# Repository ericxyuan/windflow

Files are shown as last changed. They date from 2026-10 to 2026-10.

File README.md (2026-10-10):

# Windflow desktop fan

Rev D is the current **150 mm CAD development candidate**, following the saved rotor-selection study. It uses one **T-Motor Pacer V4 P2406 Juicy 2060KV**, a custom swept/twisted five-blade impeller, one telemetry ESC, a flowing hollow enclosure and an integrated progressive outlet. Electronics retain the Rev C baseline. The active firmware, in the historical `WindflowRevC` folder, now binds calibration to the exact 150 mm rotor article with schema 5; rotor motion remains inhibited until physical commissioning requirements are met. The earlier 112 mm geometry is preserved.

Start with the [150 mm CAD decisions, validation, printing limits and remaining work](docs/rev-d-150mm-cad.md), [rotor parameters](cad/rev_d/rotor-parameters.json), [enclosure parameters](cad/rev_d/head-parameters.json) and [native editable Onshape rotor](https://cad.onshape.com/documents/5ca1b5b26cd9a4a93dde4737/w/6d3d38529391b53ad011b362/e/ac831cfb3e2f99f349f8306c). This is a development revision; no operating speed is approved for the larger rotor.

The [native adjustable airpath](https://cad.onshape.com/documents/5ca1b5b26cd9a4a93dde4737/w/6d3d38529391b53ad011b362/e/399cdd4584e017c0a30623b4) now contains seven major-profile parts and 17 inputs. [Installed front, inlet, internal and control/port review views](cad/rev_d/preview-record.json) show the separate 65-group fit geometry, including the [retained side-facing USB-C port and fit coupon](docs/rev-d-usb-access.md). Renders and native study checks do not qualify the physical fan.

The canonical repository is [ericxyuan/windflow](https://github.com/ericxyuan/windflow). The user's existing Onshape document now contains the [65-instance Rev D detailed development assembly](https://cad.onshape.com/documents/5ca1b5b26cd9a4a93dde4737/w/6d3d38529391b53ad011b362/e/57c900ab51f3a2c24ffaefca), alongside the separate native rotor and airpath studies. The [current online checkpoint](cad/onshape-rev-d-checkpoint.json) identifies the matching STEP, immutable version and screenshot evidence. Onshape's whole-assembly interference check returned six contacts entirely within the supplied HUSB238 model and no custom-part findings. The original dual-fan and earlier Rev B/C designs remain preserved.

The protected IPS screen replaces the front speed and status light bars. Its top 64 rows retain that status role; the main view shows normal power, relative wheel phase and the degrees remaining before boost control. A 24-detent turn covers normal output. At maximum normal output, another **fresh full turn** enters boost control while the panels remain open; subsequent rotation progressively closes them. Every exit, off/fault or reboot requires a fresh entry turn. The encoder sits beside the screen, turning parallel to its surface. Downward ambient lighting and long-press night mode remain. See [front controls](docs/rev-c-front-controls.md).

Start with these current deliverables; Rev C electrical documents retain the selected motor/ESC baseline, while Rev D governs the 150 mm mechanical geometry:

- [Current implementation plan and assembly development](docs/rev-d-150mm-cad.md), [full requirements audit](docs/rev-d-requirements-audit.md) and [deliverable register](docs/deliverable-status.md).
- [Current rotor, inlet, stator and one-servo boost mechanism](docs/rev-d-150mm-cad.md), [rotor-selection study](rotor_selection/README.md) and [neutral daily-use assessment](docs/rev-d-daily-use-review.md).
- [Selected bought-part BOM](hardware/rev_c/BOM.csv), [wiring and all 40 Pico pins](hardware/rev_c/wiring.md), [editable schematic](hardware/pcb/rev_c/windflow-rev-c.kicad_sch) and [schematic PDF](hardware/pcb/rev_c/windflow-rev-c-schematic.pdf).
- [15 V / 3 A USB-C PD architecture and power budget](docs/rev-c-motor-power.md). The 18 W motor/ESC cap gives a calculated 21.774 W normal-full-output scenario and 29.513 W simultaneous upper scenario; these are allowances, not measured consumption.
- [Modular firmware source](firmware/WindflowRevC), [operation and calibration](docs/rev-c-firmware.md), [source/binary validation](firmware/WindflowRevC/validation.json) and [matching motion-inhibited Pico image](firmware/dist/rev-c/WindflowRevC.ino.uf2). Current host checks cover 4,187 parser/control/safety/display assertions, 60 shipping service assertions and 73 qualified host-simulation service assertions, with a successful Pico build. No device has been flashed or operated.
- [Current CAD parameters](cad/rev_d/head-parameters.json), [nominal part validation](cad/rev_d/stage-validation.json), [motion/service checks](cad/rev_d/motion-validation.json), [mesh checks](cad/rev_d/mesh-validation.json), [checked 65-group exchange](cad/rev_d/integration-export-validation.json) and [purchased-model register](cad/model-register.md). Historical Rev C test pieces need adaptation where interfaces changed.

Actual main-board routing, the Pico cable transition, pressure daughterboard/hoses, installed looms and full fastener/tool checks remain engineering work. Motor retention, FDM rotor strength, low-speed ESC compatibility, airflow, throw, noise, temperatures, printed fits, stability and endurance require hardware evidence. A valid model, firmware build or schematic check cannot establish those results.

The earlier Noctua fan circuit, Rev B firmware, 76-instance Rev B assembly and 112 mm Rev C CAD are historical. Their reports do not qualify the 150 mm Rev D geometry. See the [historical deliverable register](docs/rev-b-deliverable-status-history.md) and [Rev C requirements snapshot](docs/rev-c-requirements-audit.md) for those checkpoints.

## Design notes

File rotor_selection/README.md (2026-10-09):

# Rotor selection — complete saved study

Study date: **9 October 2026**. This folder preserves the saved fan-selection work for Windflow, including the original user request and approval to rearrange the layout within a 200 mm total height.

Start with the [full fan shape, motor, airspeed, noise and boost analysis](docs/fan-shape-analysis-2026-10-09.md).

## Saved work

- **Report:** the full original analysis, copied byte for byte.
- **Diagrams:** both final figures in PNG and editable vector SVG form under [the study outputs](docs/fan-shape-study-2026-10-09/).
- **Calculations:** the complete [JSON record](docs/fan-shape-study-2026-10-09/calculations.json) and all three CSV tables.
- **Calculation source:** the exact [original study script](tools/analyse_fan_shapes.py), with a pinned [dependency list](tools/requirements.txt).
- **Source snapshots:** original motor/ESC specifications, rotor/head parameters, assembly/export reports, relevant CAD source and existing rotor STEP, control configuration and implementation, and consulted project documentation. Their original relative paths are preserved so the report and calculation remain self-contained.
- **Conversation:** [the original request, progress updates, layout approval and final response](history/conversation.md), plus the [final response separately](history/original-final-response.md).
- **Research history:** [all retained calls and returned text](history/research-and-tool-results.md), the structured [study log](history/study-log.jsonl), all **3 original edit patches**, readable initial and final source/report revisions, and **3 viewed-image snapshots**, including the earlier chart version.
- **References:** [source links and retrieval context](references/sources.md).
- **Verification:** copy hashes, report-link checks, runtime details and a complete file manifest.

The recommended 150 mm five-blade swept/twisted axial stage and 195 mm product height are analytical design proposals. This archive contains no new CFD, physical fan/noise measurements or revised clearance-checked production CAD.

## Reproduction

Run `tools/analyse_fan_shapes.py` from this folder with Python and the dependencies in `tools/requirements.txt`. It uses the preserved source snapshots and writes the calculations, CSV tables and figures to `docs/fan-shape-study-2026-10-09`. The original run's environment is recorded in [runtime.json](verification/runtime.json).

Copies retain the original bytes and relative structure. The original workspace files remain available. The workspace README is preserved separately as [workspace-README.md](source-snapshots/workspace-README.md) to keep this folder's index clear.

The [copy record](source-snapshots/copy-record.json) maps every copied file to its original workspace path. [manifest.json](manifest.json) records file sizes and SHA-256 hashes; it excludes itself and the verification result to avoid circular hashes.

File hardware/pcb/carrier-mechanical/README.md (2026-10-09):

# E3 carrier mechanical blank

This is a native KiCad 10 mechanical design, **not a routed electrical board or fabrication release**. It establishes the board datum, mounting holes and enforced mounting keepouts before component placement. Do not order it as a complete controller.

| Property | Value |
|---|---|
| Outline / nominal thickness | 90 × 65 × 1.6 mm |
| Mount holes | Four Ø2.4 mm NPTH, at (3,3), (3,62), (87,3), (87,62) mm |
| Mount keepout | Minimum radius 3.5 mm, all provisional copper layers; no tracks, vias, pours, electrical pads or other footprints |
| Assembly lower corner | (5,55,−106) mm |
| Global hole centres | (8,58), (8,117), (92,58), (92,117) mm |
| Populated height reserve | 22 mm from underside, leaving 20.4 mm above the nominal PCB top |
| Electrical content | No electrical nets, parts, tracks, vias or captured schematic |

Open `carrier-mechanical.kicad_pro` in KiCad. The project-local `WindflowMechanical.pretty` library and `fp-lib-table` keep the mounting footprint reproducible. Four provisional copper layers only let the mounting rules cover a possible future stackup; layer count and thickness distribution must be chosen during electrical layout.

From **PowerShell in the Windflow project folder**, regenerate with:

```powershell
& .tools/venv/Scripts/python.exe tools/build_carrier_mechanical.py
```

The runtime comes from the checked-in `tools/setup_kicad.ps1` and `tools/kicad-runtime.json`. Downloaded tools remain local. The generator reloads the board with native `pcbnew`, checks 23 mechanical properties, runs CLI DRC, exports SVG and STEP, and deliberately inserts separate copper, footprint and electrical-pad violations to prove the stored keepouts reject them. Probe boards are disposable intermediates under ignored `build/carrier-mechanical-validation/`; their reports are preserved under `negative-probes/`. The baseline DRC exits 0 with zero violations; each negative probe exits 5 with the expected keepout violation. `validation.json` records source and output hashes.

`carrier-mechanical-kicad.step` is the untouched board-only KiCad export. For an unpopulated board, this KiCad version omits outer copper/mask and exports a 1.51 mm substrate. `carrier-mechanical-cad-datum.step` separately extrudes the same validated drilled outline to the full 1.6 mm mechanical thickness and places it in the existing assembly datum. It has one valid solid, the expected 9,331.047 mm³ volume and four clear hole-axis probes. This is not a fabricated stackup model.

The [Onshape mechanical datum studio](https://cad.onshape.com/documents/5ca1b5b26cd9a4a93dde4737/w/6d3d38529391b53ad011b362/e/9b11b7d7a7402bf192647aba) visibly contains one imported part and is named **Rev B — Carrier PCB mechanical datum — UNROUTED**. It is an independent datum study; the existing 76-instance product assembly still contains its electronics reserve. Import provenance is recorded in `../../../cad/onshape-inspection.md`. Regeneration can change STEP serialization and timestamps, so the recorded import hash and later local export hash are distinguished.

Next work is schematic capture and review, final connectors and harness restraints, actual component placement, routing, ERC/DRC with schematic parity, thermal/current review, fabrication outputs and a populated-assembly check. Empty-board DRC and nominal hole alignment do not establish any of those outcomes. The remote Pico candidate is explained in [carrier-interface-study.md](../../carrier-interface-study.md).

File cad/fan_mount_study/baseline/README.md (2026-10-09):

# Frozen fan-mount negative-control baseline

These seven files are byte-for-byte copies of the checked Rev B mount inputs at repository commit `ee3ddc9cbf206eec5d336ee8c083fa07e3193e1a`, preserved before the corrected mount was adopted into the main model. Their SHA-256 values appear under `input_sha256` in the repair study's `../validation.json`.

| Archived file | Original location |
| --- | --- |
| `head-left-integral-outlet.step` | `cad/rev_b/head-left-integral-outlet.step` |
| `head-right-integral-outlet.step` | `cad/rev_b/head-right-integral-outlet.step` |
| `bellmouth-rear-inlet.step` | `cad/rev_b/bellmouth-rear-inlet.step` |
| `tpu-fan-pad-m3.step` | `cad/rev_b/tpu-fan-pad-m3.step` |
| `parameters.json` | `cad/parameters.json` |
| `build_head.py` | `cad/build_head.py` |
| `check_assembly.py` | `cad/check_assembly.py` |

The old pad and bell plate deliberately retain the defects detected by the independent repair study. Do not select them as current production print files. The archived Python scripts are provenance references; their relative dependency paths were defined for the original `cad/` directory. Run `cad/fan_mount_study.py` from the repository to reproduce the independent study rather than executing these copies in place.

The Noctua manufacturer fan STEP remains a reproducibly downloaded dependency in `cad/vendor/`, with its exact input hash recorded by the study and its download source in `hardware/sources.json`.

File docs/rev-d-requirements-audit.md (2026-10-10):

# Current requirements audit — Rev D, 10 October 2026

This audit covers all 24 original sections and subsequent instructions. The current candidate follows the complete `rotor_selection` study: a 150 mm five-blade rotor in a flowing 195 mm intended-height product, driven by the requested P2406 Juicy 2060KV and one telemetry ESC. The screen/full-turn control changes supersede the original front light bars and threshold-only boost entry. Earlier Rev B/C geometry and reports are preserved as history.

An implemented design is an inspectable artifact. It does not establish physical cooling, acoustics, structural safety or daily reliability. Unfinished PCB, wiring, pressure plumbing and mounting design remain engineering work, even when their reserves fit.

| Original requirement | Current evidence | Unfinished design or physical acceptance |
|---|---|---|
| 1. Airflow system | Actual 150 mm rotor, 152 mm throat, R12 inlet, carrier, seven curved trial stator vanes, 85 mm contraction, 104 × 94 mm outlet and fixed guards | Fan curve, volume/velocity/throw, guard losses, noise and stator A/B require measurement. The 5 m/s rotor twist input is not predicted output. |
| 2. Progressive boost | Two 55 mm panels, one feedback servo and matched symmetric linkage; 61 poses and moving-pair checks pass | 75% minimum gross aperture gives a 12.3355° endpoint. Measured torque, friction, net outlet area, motor stability and useful boost remain unqualified. |
| 3. Parametric aerodynamics | Local JSON/CadQuery detailed geometry; native Onshape seven-part, 17-input airpath and separate native rotor | Detailed interface geometry is not all contained in the native study. Assembly mates and final detailed native integration remain open. |
| 4. Fan and RPM | Original packaged-fan choice superseded by requested motor/ESC; bounded CRC UART parsing and seven pole-pair conversion | Exact shaft seat/thread/hand/depth and ESC V2.3c connector envelope require supplier or measured evidence. Compare FOC observer RPM to an independent tachometer. |
| 5. Rotary encoder | Wheel beside screen, shaft normal to screen, spin plane parallel; 96 nominal rotation/press poses pass | Confirm direction, detents, switch travel/force, thumb comfort, and desk sliding/tipping on a physical fascia sample. |
| 6. Main speed bar | Superseded by Adafruit 4311 IPS, top 64-row status band, mode/value, relative wheel phase and entry countdown | Actual readability, glare, brightness and perceived response need hardware tests. |
| 7. Ambient strip | Eight downward addressable pixels, recessed diffuser and low plinth | Complete installed retention/loom/strain relief, then test desk hot spots, temperature and night brightness. |
| 8. Startup | Nonblocking open/verify, synchronized 1.8 s ramp within a commissioned ceiling, 0.9 s return and saved settings | Distributed firmware inhibits motor motion. Hardware ramp, power interruption and flash-write timing remain untested. Saved boost returns to open normal maximum and requires fresh entry. |
| 9. Temperature | Two MCP9808 boards and ESC telemetry, configurable protection | Both current boards sit in electronics shoulders; neither measures winding temperature. Qualify locations, coupling, lag and thresholds. |
| 10. Night mode | Long press, configurable screen/ambient darkness and essential fault indication | Actual dark-room brightness and fault visibility remain physical checks. |
| 11. Magnetic grille | Four paired D42 locations, covered pockets, alignment pilots and pull tab; permanent inner finger guard. Separate [interlock pilot](rev-d-interlock-development.md) passes 1,233 nominal checks and six printed mesh checks | Interlock motion, fastener/tool access and whole-stage adoption remain design work. Magnet polarity/retention, actual switch actuation, anti-rattle behavior and coasting access need physical checks. |
| 12. TPU isolation | Separate carrier isolation ring and four replaceable feet; rigid motor carrier maintains alignment | Radial/axial fit, creep, runout and vibration transmission need printed coupons and loaded tests. |
| 13. USB-C | Battery-free 15 V / 3 A PD baseline, protected input/default-off ESC and two 5 V rails; intact sink board retained at integrated side port, current coupon passes | Main-board routing/thermal review, installed wiring/strain relief and supplied cable-boot confirmation remain open. Port/ideal-fastener geometry is checked, physical fit unqualified. Ordinary 5 V is unsupported. |
| 14. Power/status bar | Replaced by the reserved IPS status band; no battery added | Unsupported-source, brownout and fault indication need electrical tests. |
| 15. Exact hardware | Selected-component and captured-circuit BOM retained from Rev C; current mechanical decisions recorded separately | Reconcile new mounting stacks, quantities, loom lengths, supplied connectors and unmeasured motor clamp. BOM is not yet a final order list. |
| 16. Purchased CAD | Nine inherited vendor placements reproduced from source manifests; included in detailed stage | Motor/servo/encoder/ESC use explicitly labelled drawing envelopes. Historical ESC V2.2 CAD is not exact V2.3c fit evidence. |
| 17. Calibration | Recessed service shunt plus held encoder at boot; bounded serial motor/servo/display/sensor/settings commands | Schema 5 binds the exact 150 mm P2 STEP article; old/other-article calibration is rejected. Actual feedback, speed/pressure/thermal limits require commissioning. |
| 18. Firmware | Modular current source in historical `firmware/WindflowRevC`; 4,187 main assertions, 60 shipping service assertions, 73 qualified host-simulation assertions and Pico build pass | No device flashed or operated. Default motion inhibition and no approved rotor RPM remain explicit. |
| 19. FDM | Separate printed structure/TPU, split head, integral outlet, service tray; all 28 stage STL topology checks pass | Current approximately 275 × 185 mm head halves need a 300 mm class bed. A rear split for smaller beds, slicer/support review and final assembly access remain open. |
| 20. Test pieces, fixed nozzle | New M5 bore/clamp, stationary root/edge and source-matched USB side-port coupons; previous control/magnet/TPU/hinge/diffuser coupons retained as history | Adapt historical coupons to changed interfaces before claiming current fit. Final nozzle stays integral. |
| 21. Safety | Default-off motor rail, guard AND circuit, UART/temperature/current/voltage/pressure/RPM/servo logic; shipping inhibit tested | Current grille-switch geometry, populated PCB/harness and pressure taps/hoses are unfinished. Printed guards are not qualified rotor-fragment containment. |
| 22. Full CAD integration | Detailed 65-group stage has 2,080 nominal pairs with no unintended overlap; native rotor and seven-part airpath exist online | Complete main-board population/retention, looms/hoses/interlock/fasteners/tool approaches and native motion mates. A major-profile native study is not the detailed fit article. |
| 23. Critical validation | Current full motion report passes 24,278 mechanism/fixed, 1,281 moving-pair, 6,048 wheel, 3,162 screen-service and 64 rotor-envelope checks; exact 195 mm height passes | Nominal sampled geometry only. Tolerance extremes, connected service access, spin/balance, cooling/noise/thermal/torque/endurance require additional work. |
| 24. Deliverables | Current CAD sources, inhibited firmware, selected BOM, circuit/wiring/pins/power and engineering documents are indexed | Overall project remains in progress. The queue below distinguishes unfinished design from physical testing. |

## Later instructions checked

- **Rotor study first:** complete archived analysis and source snapshots reviewed before the 150 mm design. Five blades are the baseline; seven at equal solidity is a comparator, mixed flow a fallback. The complete-product 200 mm limit governs packaging.
- **Exterior and controls:** flowing hollow shoulders hide the linkage; low plinth replaces the tall electronics box. Wheel and screen share the lower front. The final outlet is integral.
- **Full-circle boost:** normal output uses 24 detents; another fresh 24 at maximum normal output arms boost with panels open, then 24 progressively adjust closure. Every exit, off, fault, service or reboot clears entry progress. Screen text and countdown make the transition visible.
- **Maintenance:** a failed backward/downward display-and-cradle path was found and preserved at `b70a79d`. The corrected display-only forward path passes; cradle replacement still needs shell opening. Loom and driver access remain separate unfinished checks.
- **GitHub identity:** canonical repository is ericxyuan/windflow. Automated commits use ericxyuan / eric.x.yuan@icloud.com for both author and committer, without changing manual defaults. Completed work is committed and remote verification uses the actual remote tip.
- **No competing work:** browser interaction and CAD mutation stay in this task. Local independent studies do not overwrite geometry under an active verification run.
- **Usage reset authorization:** maximum two existing resets across the project, only with a live five-hour reading of zero remaining and the authorized reset tool. No reset was redeemed in this run; missing readings/tooling do not qualify.

## Authorized unfinished design queue

1. Keep subsequent geometry changes matched to a fresh complete exchange and Onshape checkpoint. The current 65-instance assembly is imported, inspected and versioned; its native interference check returns six internal vendor contacts and no custom-part findings. Imported STEP has no native motion mates.
2. Complete the real supplied USB cable-boot confirmation, installed power/I2C wiring and strain relief. The retained side port and current coupon are integrated; stage/mesh/motion/export records pass for the 65-group snapshot.
3. Re-integrate grille interlock, pressure taps/hoses and installed wiring with service slack and strain relief.
4. Finish and review main PCB routing/thermal paths, keyed Pico transition and pressure daughterboard; integrate their populated geometry and retention.
5. Resolve every fastener stack, insertion/removal and driver approach; refine printer-specific splits and aiming/stability without making the final nozzle detachable.
6. Reconcile the final BOM, assembly sequence and current Onshape geometry against all changes.

Physical tests remain separate: shaft/root coupons, FDM material/process strength, guarded rotor qualification/balance/retention/tip deflection, low-speed motor/ESC compatibility and true RPM, pressure/swirl/stator comparison, normal/boost cooling/throw/noise, servo load/jam/endpoints, voltage/inrush/thermal/fault behavior, grille retention, screen/encoder feel/night mode, stability and endurance. None has been substituted with a render or software assertion.

[Deliverable register](deliverable-status.md), [current CAD and assembly development](rev-d-150mm-cad.md), [neutral daily-use review](rev-d-daily-use-review.md).

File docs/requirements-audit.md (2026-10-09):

# Windflow requirements audit

This register compares the complete original desktop-fan brief with the current artifacts and the later GitHub, screen and encoder instructions. It records implementation at its actual level: source, generated geometry, imported assembly, analytical circuit or measured hardware. It is not a manufacturing release.

The pushed screen/control checkpoint is `8ede72d`; the reviewed interaction improvements are pushed as `422bd7b`. They include a 24-detent normal-power range, clearer screen hierarchy, readiness prompts and cosmetic-settings handling. Current workspace work adds the routed encoder board, mechanical carrier/interface study, corrected fan stack, M1.6 Pico mounts and grille interlock. The control/UI/service changes pass source tests, production rendering and Pico compilation recorded in the build provenance. Independent board/study checks do not establish a current complete assembly pass; adoption and whole-product checking remain necessary. Use [deliverable status](deliverable-status.md) and [build provenance](../firmware/dist/build-validation.json) for current counts and hashes; this audit deliberately does not duplicate changing test totals.

## Status meanings

| Status | What it establishes |
|---|---|
| Implemented | The stated source, geometry or document exists and has the indicated verification. It does not establish physical performance. |
| Partial | A useful implementation exists, but an achievable design or integration requirement remains open. |
| Unfinished design | Required circuit, geometry, routing, mating or assembly work is absent or not adopted. This work can continue without physical hardware. |
| Physical testing | The design has a starting value or analytical rationale; measurements are needed to qualify it. |
| In progress | A current workspace change or independent study is not yet accepted into the checked complete assembly/release. |

## Later instructions that change the original brief

| Later instruction | Current treatment |
|---|---|
| GitHub username is `ericxyuan` | The canonical project URL is [ericxyuan/windflow](https://github.com/ericxyuan/windflow). Active repository/document links were updated. Historical evidence remains historical. |
| Replace multiple front light bars with a clear screen | Adafruit 4311, 320 × 240 landscape IPS, replaces the main speed pixels and separate RGB status lamp. The downward ambient strip remains. The screen has a clear protective window, not an LED diffuser. |
| Reserve the top screen section for the replaced light-bar functions | The top 64 rows show normal power, boost and power/system/fault information. |
| A full turn after normal maximum enters boost control | Normal maximum keeps the panels open. A fresh 24-detent / 360° upward entry turn enables boost at zero closure; subsequent rotation changes boost. Crossing an ordinary percentage alone cannot enter boost. |
| A new full turn is required after leaving boost | Returning boost to zero exits boost control and resets entry progress. Off, fault, service and reboot also clear authorization. Re-entry cannot accumulate while the panels are reopening or safety limits are active. |
| Show encoder position and distance to boost entry | The screen shows relative wheel phase and remaining degrees. The incremental encoder cannot measure an absolute shaft angle; its relative reference is explicitly documented. |

The full-turn instruction supersedes the original single continuous normal/boost threshold behavior. `boostThreshold` remains an internal stored-setting split, not permission to constrict the outlet. Likewise, a saved boost request restores normal maximum with open panels instead of bypassing the required new entry turn.

## Original brief, all 24 sections

| Section | Current implementation | Remaining requirement and evidence |
|---|---|---|
| 1. Core airflow | **Partial + physical testing.** One real Noctua fan, straight duct, true rounded inlet, gradual section transition, fixed guards and a trial radial straightener exist. | Useful velocity, throw, volume, noise and the straightener benefit are unmeasured. Compare the seven-vane insert against a locating ring without vanes; retain it only for a measured benefit. [Airflow rationale/test plan](physical-validation.md), [implementation plan](implementation-plan.md). |
| 2. Progressive boost | **Partial + physical testing.** Two symmetric converging panels, common yoke, one feedback servo, metal hinges, hard limits and a linkage cover are modeled; firmware progressively closes them. The later full-turn entry behavior is implemented. | Finish real fastener/tool/harness integration and Onshape motion mates. The initial 75% gross-area endpoint and analytical pressure torque are not qualified operating values. [Mechanism](../cad/mechanism-notes.md), [control source](../firmware/Windflow/Control.cpp). |
| 3. Parametric aerodynamics | **Partial.** Native Onshape inlet/stator/nozzle parameters and local CAD parameters exist. | The native aerodynamic study does not drive the detailed imported shell, hinges or mechanism. Complete the intended linked parametric behavior, or clearly identify which values require regenerating/importing local CAD. [Onshape record](../cad/onshape-inspection.md), [parameters](../cad/parameters.json). |
| 4. Fan and RPM feedback | **Implemented in selection/source; physical testing.** NF-A12x25 G2 PWM, tach input, low/abnormal-RPM supervision and pressure-based restriction protection are selected. | Confirm two tach pulses/revolution, starts at minimum PWM, operating RPM and fault timing. Regulated RPM does not prove airflow; the added pressure sensor addresses a separate quantity. [BOM](../hardware/BOM.md), [firmware](firmware-operation.md). |
| 5. Rotary encoder | **Implemented geometry/source; physical testing.** Horizontal Bourns PEC11H shaft, exposed up/down wheel, short on/off press, long night press and guarded service entry exist. | Confirm direction, detent capture, lateral press travel and base stability. The revised 24-detent normal range is implemented and source/build tested. [Controls](screen-and-controls.md), [base CAD](../cad/build_base.py). |
| 6. Main speed display | **Superseded by the screen; implemented source/CAD, physical testing.** Blue normal, amber entry and purple boost have explicit text labels. | The parent has implemented larger primary power/boost/countdown readouts and simpler labels; production renderer equivalence and final Pico compilation pass. Readability, glare, contrast and brightness need a physical desk-distance check. [Renderer](../firmware/Windflow/DisplayLayout.cpp), [preview](images/display-preview.png). |
| 7. Downward ambient strip | **Implemented geometry/source; partial integration.** Recess, diffuser, keeper, eight-pixel stick and dimming remain. | Finish routed harness, strain relief and the populated tray's removal path. Verify illumination, current and thermal clearance. [Base CAD](../cad/build_base.py), [lighting](../firmware/Windflow/Lighting.cpp). |
| 8. Startup sequence | **Implemented and software-tested; physical testing.** Power qualification, open-position verification, first rendered frame, smooth 1.8 s up / 0.9 s return and saved normal setting are implemented. Unsafe/night/off conditions limit or skip the ramp. | Verify the physical order of screen/ambient activation and fan motion, timing, off cancellation and voltage/temperature limits. Saved boost deliberately returns to open normal maximum under the later entry instruction. [Firmware operation](firmware-operation.md), [controller](../firmware/Windflow/Control.cpp). |
| 9. Temperature protection | **Implemented circuit/source; partial thermal integration + physical testing.** Two MCP9808 channels and configurable warning/trip behavior exist. | Establish actual coupling to the regulator region and sensor lag; the second board measures base air, not a demonstrated motor winding temperature. Verify protected junction temperatures and avoid nuisance trips. [BOM](../hardware/BOM.md), [circuit review](../hardware/circuit-review.md). |
| 10. Night mode | **Implemented source; physical testing.** Long press dims/disables screen and ambient lighting, suppresses unnecessary startup animation and retains essential fault indication. | Measure actual low-level brightness, flicker, darkness at reset/reconnect and useful confirmation of the long press. [Display source](../firmware/Windflow/Display.cpp), [calibration](calibration.md). |
| 11. Magnetic front grille | **Implemented geometry; partial interlock integration + physical testing.** Four attracting magnet pairs have pockets, adhesive allowance and screw-retained keepers; a separate fixed guard remains. | Finish grille-present switch mounting/contact travel. Measure retention through the real skins/gap, rattle, peel removal and guard strength. [Head CAD](../cad/build_head.py), [physical plan](physical-validation.md). |
| 12. Vibration isolation | **Partial; corrective study in progress.** Separate TPU fan pads/feet and a metal limiter concept exist. | The checked pad bore was Ø3.4 while the limiter OD was Ø4.0; the limiters were absent from the whole-assembly check. Adopt the corrected stack and repeat checks with all four tubes, washers and screws. Then measure vibration, creep and alignment. [Fan mount study](../cad/fan_mount_study/), [head CAD](../cad/build_head.py). |
| 13. USB-C power | **Implemented selection/analysis; unfinished PCB design + physical testing.** 15 V / 2 A PD, fixed 12 V fan rail, separate 5 V rails, fusing, eFuse and default-off loads are specified. No battery is added. | Capture/route the circuit, finish connectors/strain relief and verify rails, inrush, shorts, heat and unsupported-source behavior. [Wiring](../hardware/wiring.md), [budget](../hardware/power-budget.md), [review](../hardware/circuit-review.md). |
| 14. Power/charging bar | **Superseded by screen status; implemented source.** USB/system/fault status replaces charging indicators because there is no battery. | A fault display requires its healthy logic supply; no display is promised from an absent rail. Confirm power-status presentation with real supported and unsupported sources. [Screen controls](screen-and-controls.md). |
| 15. Exact hardware | **Partial.** Major electronics and mechanical components have named models/specifications and an E3 BOM. | Freeze adopted carrier connectors, module interconnection and final fastener quantities. Confirm supplied servo variant, regional PSU ordering and current stock before purchase. [BOM](../hardware/BOM.md), [carrier study](../hardware/carrier-interface-study.md). |
| 16. Purchased CAD | **Partial.** Manufacturer models for fan, Pico, regulators, PD board, sensors, ambient stick and screen are integrated; provenance is recorded. | Servo/encoder remain drawing-based envelopes. The older screen STEP does not establish the current EYESPI rear connector. Continue accurate model attempts and verify actual delivered interfaces. [Model register](../cad/model-register.md). |
| 17. Calibration mode | **Implemented source/instructions; physical testing.** Recessed jumper plus boot hold, bounded fan/servo tests, five captures, pressure zero, RPM evidence, screen patterns, ambient tests and stored settings exist. | Validated brightness changes now preserve valid commissioning; production service tests verify that the other exposed fields still invalidate evidence and that save interlocks remain effective. [Service source](../firmware/Windflow/Service.cpp), [calibration](calibration.md). |
| 18. Modular firmware | **Implemented and compiled; current source/render/build validation passed.** Input, control, hardware, lighting, display, calibration and storage are separate modules with timed cooperative work. | Current interaction/service tests and rebuild pass; repeat affected checks after further edits. Measure real maximum loop delay, IRQ capture, SPI and flash-write responsiveness. [Firmware operation](firmware-operation.md), [provenance](../firmware/dist/build-validation.json). |
| 19. FDM design | **Partial.** Split structural head, integral outlet, separate moving parts, accessible inserts and proposed print orientations exist. | Finish the missing interfaces and complete slicer review of supports, thin vanes, hinge bridges and layer strength. Nominal valid B-reps are not proof of successful printing. [Printing](printing-and-assembly.md). |
| 20. Test pieces | **Implemented geometry; physical testing.** Encoder, hinge, yoke, magnet, insert, TPU and screen coupons exist. The product outlet remains integral with the head; the nozzle fixture is only a test piece. | Print/measure coupons using the final materials and stack; adopt the results into the controlled geometry. [Printing](printing-and-assembly.md), [prototype folder](../cad/prototypes/). |
| 21. Automatic protections | **Implemented source/analytical circuit; partial physical interfaces + physical testing.** Stall, pressure, servo tracking, temperature, guard and power protections override requests and cosmetics. | Interlock mechanics, sensor plumbing and the real PCB are not complete. Verify shutdown/coast behavior, safe acknowledgment, back-powering and fault timing on controlled fixtures. [Firmware](firmware-operation.md), [electrical review](../hardware/circuit-review.md). |
| 22. Final CAD integration | **Partial.** Current checked E3 import contains the main structural assembly and purchased models; separate local studies continue. | Adopt real carrier population, harness/tubes, interlock, complete fan/fastener stacks and motion mates, then repeat source-matched checks and import/reconcile the accepted result. [Status](deliverable-status.md), [Onshape record](../cad/onshape-inspection.md). |
| 23. Final validation | **Partial.** Software, renderer, nominal geometry and selected insertion checks have evidence with stated exclusions. | Resolve unfinished design before treating hardware measurements as the only remaining work. Physical performance, assembly, reliability and safety tests remain unexecuted. [Physical plan](physical-validation.md). |
| 24. Deliverables | **Partial.** All requested subjects have project artifacts or a progress record, but several artifacts remain development specifications/studies. | The following table identifies each required deliverable without equating a document with a finished design. |

## Required deliverables, all 22

| # | Deliverable | Current state / controlling artifact |
|---|---|---|
| 1 | Updated Onshape CAD | **Partial:** imported E3 assembly plus native aerodynamic features; full parameter linkage/motion/interface work remains. [Onshape record](../cad/onshape-inspection.md). |
| 2 | Purchased-component CAD | **Partial:** substantial manufacturer integration; declared approximate servo/encoder and current screen connector limits. [Register](../cad/model-register.md). |
| 3 | Complete firmware | **Implemented prototype source/build:** current interaction/service edits pass the recorded host/render/build verification. [Firmware](../firmware/Windflow/). |
| 4 | Exact BOM | **Partial:** named electrical population exists; adopted harness and final product fastener count remain. [BOM](../hardware/BOM.md). |
| 5 | Wiring diagram | **Implemented specification; unfinished schematic/PCB:** net-level diagram is not fabrication data. [Wiring](../hardware/wiring.md). |
| 6 | Pin assignment | **Implemented:** Pico GPIO/physical pins and selected circuit nets. [Wiring](../hardware/wiring.md). |
| 7 | Power budget | **Implemented analysis; physical testing:** includes LEDs, screen allowance, servo and conversion losses. [Budget](../hardware/power-budget.md). |
| 8 | USB-C architecture explanation | **Implemented:** fixed PD request, rail/protection architecture and no battery. [Budget](../hardware/power-budget.md), [review](../hardware/circuit-review.md). |
| 9 | Airflow explanation | **Implemented rationale; physical testing:** baseline and comparison criteria. [Plan](implementation-plan.md), [validation](physical-validation.md). |
| 10 | Bell-mouth explanation | **Implemented:** true quarter-circle geometry and radius/throat rationale. [Validation](physical-validation.md), [CAD](../cad/build_head.py). |
| 11 | Straightener explanation | **Implemented trial rationale; physical testing:** short radial insert; no unearned honeycomb benefit claim. [Validation](physical-validation.md). |
| 12 | Boost mechanism explanation | **Implemented analytical study; partial final integration:** kinematics, stops and torque limits. [Mechanism](../cad/mechanism-notes.md). |
| 13 | Normal/boost mapping | **Implemented and source/build tested:** full entry and fresh re-entry remain mandatory. [Controls](screen-and-controls.md). |
| 14 | Temperature logic | **Implemented source/documentation; physical testing:** thresholds are sensor-location values. [Firmware](firmware-operation.md). |
| 15 | Tach/stall logic | **Implemented source/documentation; physical testing:** regulated tach is distinct from airflow. [Firmware](firmware-operation.md). |
| 16 | Startup documentation | **Implemented:** includes safety/night/off exceptions and open-normal restoration. [Firmware](firmware-operation.md). |
| 17 | Calibration instructions | **Implemented prototype procedure:** service/cosmetic save behavior is reconciled; physical measurements remain required. [Calibration](calibration.md). |
| 18 | Printing instructions | **Partial release:** orientations/coupons exist; final interfaces and slicer/coupon acceptance remain. [Printing](printing-and-assembly.md). |
| 19 | Assembly instructions | **Partial:** intended sequence exists; a complete connected product cannot yet be assembled from released artifacts. [Printing](printing-and-assembly.md), [electronics](electronics-assembly.md). |
| 20 | All nonprinted parts | **Partial:** BOM lists purchased electronics, metal hardware, window and consumables; final quantities/interconnects remain. [BOM](../hardware/BOM.md). |
| 21 | Physical tuning parameters | **Implemented starting values:** geometry, PWM, LUT, pressure/temperature and brightness settings are listed; adoption requires measurements. [Parameters](../cad/parameters.json), [calibration](calibration.md), [validation](physical-validation.md). |
| 22 | Physical-testing uncertainties | **Implemented register:** measurement methods and acceptance targets exist. [Validation](physical-validation.md). |

## Ordered completion work and acceptance

1. **Accept the control/UI/service revision.** Repeat control/input/display/service tests and the Pico build; regenerate the production-rendered preview; compare source/UF2 hashes. Demonstrate 24 normal detents from zero to maximum, 23 entry detents without closure, the 24th enabling boost at zero, progressive subsequent closure, fresh entry after exit, and safe blocked-entry prompts. Cosmetic changes must preserve valid mechanical commissioning; unsafe changes must still clear affected evidence.
2. **Adopt the fan stack and physical interfaces.** Include four limiters, real head/washer/thread envelopes, tubing, interlock/contact travel, clamps and service slack. No known nominal collision may be left as a physical uncertainty. Check insertion and tool approaches with the actual occupied paths.
3. **Finish the electrical design.** Adopt one real module interconnection scheme, capture the circuit and reference designators, complete ERC/DRC, route current/thermal paths, and generate fabrication/placement data for all custom boards. An electrically empty mechanical board is not an electrical acceptance result.
4. **Reconcile final CAD and purchasing data.** Integrate the populated boards/connectors/harness, finish Onshape mates/parameter behavior, repeat affected whole-assembly/service-path checks, and freeze the print manifest/BOM/fastener schedule against that revision.
5. **Print and dry-assemble the controlled prototype.** Resolve coupon fit, layers/supports, insert strength, grille operation, free mechanism travel and one-handed control stability before powering the loads. Record failed fits and change geometry rather than forcing assembly.
6. **Qualify electronics and performance on hardware.** Verify rails and transients first, then commission sensors/servo/tach, perform controlled faults, and measure flow/throw/noise/thermal behavior/endurance under [the physical plan](physical-validation.md). Report raw measurements and uncertainty, including comparisons with and without the straightener.

The project should be considered complete to the extent possible without hardware only after items 1–4 have accepted artifacts and all remaining item 5–6 dependencies are explicitly recorded as physical work. At the current review those achievable design items remain open.

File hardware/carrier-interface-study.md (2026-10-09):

# Carrier interfaces — design study, 5 October 2026

The carrier is mounted separately from the Pico and three regulators. The prior socket rows in the BOM do not establish a physical connection between those separate tray positions. This study defines a candidate harness and actual PCB mounting geometry; it does not replace the E3 circuit specification or qualify a fabrication release.

## Mechanical board

The main carrier outline is 90 × 65 × 1.6 mm, with four Ø2.4 mm NPTH holes at board coordinates (3,3), (3,62), (87,3), (87,62). Its lower corner in assembly coordinates is (5,55,−106), giving global hole centres (8,58), (8,117), (92,58), (92,117). The bottom face is −106 and the top face is −104.4 mm. These match the existing tray supports; the PCB is separate from the 22 mm volume reserved for populated electronics.

The mechanical KiCad files are in `pcb/carrier-mechanical/`. They have no power/control netlist or routed circuit. Mounting keepouts and a board outline are concrete design work; an empty-board DRC result cannot establish electrical safety, current handling or circuit correctness.

## Remote Pico candidate

Use four **Samtec TSW-120-07-G-S** strips: two on the Pico and two on the carrier. Replace the former carrier SSW-120 socket concept with removable cables between male headers. The selected TSW post is 5.84 mm, within the IDSS documented 5.59–6.22 mm insertion range. [TSW product](https://www.samtec.com/products/tsw-120-07-g-s), [IDSS catalogue](https://suddendocs.samtec.com/catalog_english/idss.pdf).

Two **Samtec IDSS-20-D-04.00-G** cable assemblies are the base candidate: single-row, twenty positions, sockets at both ends, 101.6 mm assembled length, gray 28 AWG ribbon, gold default contacts. Fit **PK-06** keys to both ends of the left cable at position 12 and both ends of the right cable at position 10. The same keys can be ordered through the documented P12/P10 configuration; confirm the complete multi-option order code with Samtec before purchase. Remove the corresponding male contacts on both boards. [Manufacturer series print](https://suddendocs.samtec.com/prints/idsx-xx-x-xx.xx-xxx-xxx-mkt.pdf).

| Carrier row | Cable position | Pico physical pin | Key / unused positions |
|---|---|---|---|
| J15, logical pins 1–20 | n | n | Position 12 is blocked; GP9 is unused. |
| J16, logical pins 1–20 | n | n + 20 | Position 10 is blocked; RUN, physical pin 30, is unused. |

Carrier pins corresponding to Pico physical 35 (ADC_VREF), 37 (3V3_EN) and 40 (VBUS) have no circuit connection. They must not connect to ground or a power rail. The cable still contains those conductors; keep their unused landing pads short. All eight ground/AGND positions are retained. This connects only the documented Pico low-current supply and signal nets; fan, servo and LED power never travels through the Pico or ribbon. Continuity must follow pin numbers at both ends, including the opposite numbering directions of the Pico rows. Do not infer pin order from a view of the underside or ribbon color alone.

The different blocked positions prevent a fully seated row swap or reversal when every required key and removed male contact is present. They do not guarantee resistance to forced or offset insertion. A printed retention/strain clamp and insertion review remain required. Disconnect power before attaching or removing these looms.

Candidate carrier row centres are global (13,86.5) and (22,86.5); the Pico row centres are (−53.39,86.5) and (−35.61,86.5). The separate CAD study is `../cad/interface_study/remote-pico-candidate.step`. Its ten socket/header/corridor envelopes pass 555 nominal collision checks against the revised base components and each other, with exit 0 and no intersections. The report records source/input hashes. Bends, service slack, clamp geometry and complete cable shape are absent. Restrict future components beneath the ribbon corridor to 18 mm above the carrier top; pressure tubing introduces lower keepouts on its actual route. Validate both again after component placement.

The Pico mount now uses four Accu SSCF-M1.6-10-A2 cap screws and HPN-M1.6-A4 nuts, with 1.8 mm printed holes and 3.3 mm AF nut pockets. The maximum 3 mm head leaves 0.42 mm nominal clearance to the adjacent header body. A driver no more than 3.4 mm in outside diameter leaves 0.22 mm nominal lateral clearance. Unplug both IDSS sockets before accessing the screws; no washers are fitted. These drawing-based clearances still need print and supplied-part qualification. This mount is adopted in local base geometry; the 3 October 76-instance Onshape checkpoint has not yet received it.

The full SPI route includes the Pico ribbon, carrier traces and J6 screen loom. Target their combined wire length at no more than 150 mm rather than treating each harness independently as 150 mm. The 101.6 mm Pico candidate leaves under 48.4 mm for J6 wire; geometry and service slack must establish whether that is feasible. If not, select a shorter supported Pico cable or revise the routing and SPI rate after timing/edge tests. This is a design limit, not measured signal-integrity evidence.

## Regulator connection to resolve in the schematic

Pololu explicitly permits wires soldered directly to its D24V22Fx pads for a compact installation. Use mechanically restrained, labeled pigtails from the independently screwed modules to carrier power connectors; remove the former assumption that a carrier-mounted five-pin socket directly holds each remote module. Keep each EN pad unconnected. REG1 and REG3 need VIN, GND, VOUT and PG; REG2 needs VIN, GND and VOUT only. [Manufacturer connection instructions](https://www.pololu.com/product/2858).

Choose keyed power connectors and their placement during schematic capture, accounting for 22 AWG power pairs, PG isolation, insertion access and the different output voltages. The complete ordered connectors, strain clamps, harness lengths and populated-board placement are still unfinished. The existing BOM socket rows remain provisional until that revision is reconciled; this candidate study must not be used alone to order or assemble the electronics.

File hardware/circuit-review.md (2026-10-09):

# Electrical circuit review — E3

Reviewed 2026-10-05 against the selected module documentation and the Pico firmware, including the 5 V grille-contact loading and 3.3 V BUF4 interface. This is an analytical/netlist review. Main-carrier capture is in progress; no carrier PCB has been routed, manufactured, populated or electrically tested. The physical assembly is therefore not yet an electronics release.

## Concrete corrections made

| Previous issue | Correction retained in E3 | Firmware consequence |
|---|---|---|
| Always-on 5 V servo buffer could drive an unpowered servo | Dedicated BUF3 on the switched servo supply; input/output pulldowns | Same GP8, noninverting |
| 10 nF switch CT with 470 uF reservoir caused about 2.19 A charging current | CT increased to 100 nF; 330 ohm external QOD resistors defined | 50 ms pixel power-up settle |
| Live divider nets and filter charge could reach an unpowered Pico | Three TMUX1511 channels enabled by a 3.3 V supervisor; filter capacitors on source side | No GPIO added |
| Servo divider unnecessarily loaded the internal feedback pot with 20k | 100k upper, 100k lower, 1M ADC-side pulldown | Recalibrate raw position LUT |
| Divider values, passive counts and firmware scales disagreed | Reference-designator netlist; bus scale 11.1, logic scale 2.1 | Current screen/input schema 3 requires recommissioning; voltage scales remain11.1/2.1 |
| Raw PD output drove bulk capacitance without controlled startup | EF1 before reservoir and regulator bank; current limit and OVP | No GPIO added; low-voltage input may leave status dark |
| Fan fuse order code was incorrect; connectors were unspecified sets | Corrected 0451.500MRL and fixed electrical harness quantities/pin order | None |
| TFT BL 2.2k pulldown left 0.60 V during high-impedance reset, above some BSS138 minimum thresholds | R56=1k at the screen; spare BUF2 channel 3 drives BL, with R59=100k GPIO-side pulldown | Same GP16 and noninverting 2 kHz PWM; powered reset drives BL LOW |
| Grille gold contact at3.3 V /0.70 mA was below Omron's1 mA /5 V reference load | R5=3.9k to5 V; BUF4 SN74LVC1G17DBVR at3.3 V with5.5 V tolerant input/Ioff, C31/C32 and R60 | Same GP15 and active-low guard logic; never connect raw5 V to GPIO |

The specified Nexperia buffers characterize input leakage with supply at zero; the separate switched supplies remove an always-on buffer output from the servo and pixels. Their outputs are not universally power-off tolerant and must not be driven by another powered source. [Quad buffer](https://assets.nexperia.com/documents/data-sheet/74AHC_AHCT125.pdf), [single buffer](https://assets.nexperia.com/documents/data-sheet/74AHC_AHCT1G125.pdf).

## Voltage and current checks

| Check | Calculation / design result | Practical limit |
|---|---|---|
| Bus ADC at 15 V | 15/11.1 =1.351 V | Calibrate against DMM |
| Bus ADC at 18 V | 18/11.1 =1.622 V | EF1 should already have disconnected above its OVP threshold |
| Logic/servo ADC at 5.25 V | 5.25/2.1 =2.50 V | Below healthy 3.3 V; servo feedback cannot exceed its supply in normal operation |
| ADC disconnected, input still live | Mux source bus divider is 100k/10k; 15 V produces 1.364 V before mux | No stored 100 nF capacitor remains directly on ADC side |
| Supervisor threshold |3.07 V nominal, then 20 ms release delay | Scope rapid collapse/slow ramp to verify sequencing on built board |
| EF1 OVP |1.19×(1+130/10)=16.66 V nominal | About 16.08–17.47 V allowing 1% resistors, reference range and 100 nA leakage; verify trip on bench |
| EF1 UVLO |1.19×(1+100/15)=9.12 V rising | Firmware's 14–16 V and PD check remain stricter operating qualification |
| EF1 current limit |12/8.06=1.489 A | Account for reference and resistor tolerance; not instantaneous disconnect |
| Selected input budget |12.994 W /15 V=0.866 A | At 14 V approximately 0.928 A before efficiency changes, below assumed 1.41 A low current limit |
| REG2 |0.48 A ambient +0.10 A screen +0.15 A housekeeping =0.73 A | Nominal 2.5 A is thermally dependent; screen 100 mA is an allowance |
| Ambient load switch |0.48 A steady; approximately 0.70 A including capacitor ramp | Below 2 A specified DBV operating current under stated conditions; PCB copper and actual startup must be verified |
| Fan |12 V, 0.15 A; fixed voltage buck | Check transient remains below 13.2 V fan maximum |
| Screen CS/RST |Onboard 10k pullups to 5 V VIN; BUF2 provides noninverting 5 V outputs | Never connect the module CS/RST directly to Pico GPIO during 5 V operation |
| Screen BL |Onboard 10k to 3.3 V, R56=1k to GND, BUF2 channel 3 via R55=330 ohm: nominal gate HIGH 3.748 V, ideal LOW 0.0799 V, disconnected output 0.300 V | Conservative BUF2 VOL=0.44 V gives gate about 0.403 V; verify actual off leakage/light, HIGH drive and reset sequencing |

These calculations do not establish a single-fault-certified product. A failed regulator passing its input to a 5 V rail is outside the demonstrated protection claim. Do not infer that a TVS holds the bus to its standoff voltage, or that load-switch thermal shutdown is a current limiter. EF1 monitors input voltage; it is not a separate overvoltage detector on each regulator output.

The [TMUX1511](https://www.ti.com/lit/ds/symlink/tmux1511.pdf) accepts the divided signals while unpowered; SUP1 prevents normal connection until its [3.3 V threshold](https://www.ti.com/lit/ds/symlink/tps3808.pdf) is met. EF1 limits input current and isolates the main reservoir. OVP and slew values above are circuit calculations based on the [TPS26600](https://www.ti.com/lit/ds/symlink/tps2660.pdf), not measured trip accuracy.

## Screen changes and circuit checks

E3 removes the 16-pixel main display and Kingbright status lamp, preserves the 8-pixel ambient chain, and adds an Adafruit 4311 ST7789 IPS screen. The screen is on unswitched REG2 so thermal/guard faults can disable SW3 while retaining visible fault indication when logic power remains available. BL uses GP16, on a separate PWM slice from fan GP6 and servo GP8. GP7 is digital TFT reset.

The current vendor EYESPI schematic shows 10k pullups from CS and RST to VIN. BUF2 is reused on REG2 for those two signals instead of deleting it: each Pico-side input has a 10k pullup to 3.3 V, and the 5 V outputs meet the module's input levels without exposing Pico pins to 5 V. Its third channel drives BL noninverting: A9=GP16 with R59=100k to GND, OE10=GND, Y8 through R55=330 ohm to BL. R56 is **1k**, replacing the earlier 2.2k, at the display end. Adafruit explicitly allows 3–5 V logic at BL. The onboard Q1 is specified only as generic BSS138 in the SOT23-R library device; no manufacturer/orderable-part attribute establishes which transistor is fitted. The library's NXP BSS138PW suggestion is not a fitted-part guarantee and even refers to a different package. [Current schematic](https://github.com/adafruit/Adafruit-2.0-inch-240x320-TFT-PCB/blob/master/Adafruit%20EYESPI%202.0%20Inch%20240x320%20IPS%20TFT.sch), [BL interface](https://learn.adafruit.com/2-0-inch-320-x-240-color-ips-tft-display/pinouts).

The stronger pulldown is justified by a real variant limit: Diodes' BSS138 has minimum VGS(th)=0.5 V at 250 uA, whereas the earlier disconnected gate calculation was 0.60 V. Threshold is not a guaranteed optical-darkness limit, and neither typical curves nor a generic part name prove hot off leakage. A direct 3.3 V GPIO with the new 1k pulldown would give only 2.50 V nominal HIGH and draw 2.42 mA; the spare 5 V buffer improves HIGH margin without changing PWM polarity or loading GPIO with that current. [Diodes BSS138 characteristics](https://www.diodes.com/datasheet/download/BSS138.pdf).

For an ideal buffer output `Vdrv`, the nominal network is `Vgate=(Vdrv/330 +3.3/10000)/(1/330 +1/1000 +1/10000)`. It gives 3.748 V HIGH at Vdrv=5 V, 0.0799 V LOW at Vdrv=0, and 0.300 V with its output disconnected. During normal powered reset R59 holds BUF2 LOW; the 0.300 V result describes a disconnected/high-impedance output, not normal powered reset. BUF2's conservative −40 to +85 C bounds at VCC=4.5 V and an 8 mA test load give minimum VOH=3.8 V and maximum VOL=0.44 V: using those levels yields gate HIGH 2.868 V and LOW 0.403 V with nominal resistors. Assuming 1% for all three resistors and ±2% for the module's 3.3 V, the latter rises to approximately 0.406 V; onboard tolerances must be confirmed before treating that assumption as a bound. The full −40 to +125 C VOL limit of 0.55 V instead gives 0.483 V nominal, reinforcing the need for actual thermal/optical qualification. R59's maximum 0.2 V from 2 uA specified input leakage at 125 C remains below the 0.8 V input-LOW limit. The nominal HIGH path is about 3.79 mA, comfortably below the buffer's characterized 8 mA load; reserve about 19 mW within the existing logic/buffer power allowance. Power-ramp output levels below the buffer's 4.5 V operating range are not guaranteed and require a scope/reset-flash test. [Buffer characteristics and pinout](https://assets.nexperia.com/documents/data-sheet/74AHC_AHCT125.pdf).

R50–54=33 ohm are initial series damping values, not proof of signal integrity. Keep the eight-wire display harness under 150 mm and verify SPI edges, reset, unplugging and white-screen current. The existing 3.3 V Pico regulator supplies only logic inputs, not the screen or backlight load. SDCS is unused and its onboard 10k VIN pullup keeps the unpopulated card slot deselected. The glass needs a clear protective window; no LED diffuser belongs over the visible screen. The old main optical hardware and status lamp are superseded.

## Layout requirements for the 90 x65 x22 mm allowance

The allowance is plausible for the carrier semiconductors, passives and edge connectors, with the Pico, three regulator modules and PD board mounted separately. It has **not** been verified by a PCB placement or CAD collision check. Reserve the whole volume until that verification. Put heavy reservoirs and power connectors at the board edge, and the ADC/dividers away from switch nodes and servo wiring.

Use a professionally fabricated FR4 carrier, preferably four layers with continuous system-ground reference and short high-current loops. EF1 requires an exposed-pad footprint and thermal vias into its isolated RTN copper region; follow TI's thermal layout rather than treating it as a leaded adapter. It is not suitable for a solderless breadboard. Keep all RTN-referenced control parts with EF1. Do not connect that thermal island to the general ground pour.

Required footprint families: TPS26600 PWP16/HTSSOP16 exposed pad; TPS22810 DBV/SOT23-6; TPS3808 DBV/SOT23-6 with its distinct pin mapping; TMUX1511 PW/TSSOP14; Nexperia BUF1/2 SO14 (ambient and display CS/reset/backlight); BUF3 SOT353-1/TSSOP5; 2N7002 SOT23; SMA SS14; SMB TVS; 2410 fuses; 0603 signal passives; 1206 QOD resistors; actual radial capacitor lead pitches; specified through-hole connectors. Verify every manufacturer's land pattern and pin 1 orientation in schematic capture. Do not equate a shared package name with a shared pinout.

## Release checks still required

1. Capture the specified schematic and all reference designators, perform ERC, place/rout the carrier and complete DRC. Compare its board outline and mating plugs to the reserved CAD volume. No unreviewed auto-routing or undersized thermal adapter substitutes.
2. Inspect solder joints, measure every rail and check module PG levels before connecting the Pico or loads. Scope raw/protected PD input, 3.3 V and each switched rail on connection/disconnection.
3. Verify no appreciable phantom supply voltage on servo/LED rails with them disabled and MCU running. Scope ADC pins during slow and abrupt power removal; check the supervisor actually isolates before the MCU rail falls below the signal.
4. Check source behavior with 5 V-only, 9 V, 12 V and correct 15 V PD sources. Verify negotiated current/voltage reporting, disabled loads under an unsupported contract, and recovery without repeated stalled startup.
5. Measure simultaneous full fan, quickest servo movement and full-white ambient plus maximum screen-backlight current/temperature. Test short protection with a current-limited bench supply and isolated dummy loads before any installed harness short test.
6. Verify temperature sensor coupling and trip latency; reported 55/65 C thresholds are sensor-location values, not proof that every IC junction stays below a limit. Check EF1 and SW3 temperatures separately from the regulator cluster.
7. Verify real servo feedback monotonicity, no change in settled angle when its measurement network is attached, jam timeout, opening direction and endpoint travel. Inspect grille interlock while the rotor coasts.

Screen-specific release checks also require readable text at expected desk distance, low night brightness without flicker, correct 320 x240 landscape orientation, no reset flash, and no safety-loop starvation while updating the screen. Every electrical result is currently **not measured**. The fixed inner guard, fuses and hardware default-off states are part of the build, not optional substitutes for these checks.

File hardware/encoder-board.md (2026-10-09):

# E3 encoder daughterboard — prototype P1

The passive daughterboard for the Bourns **PEC11H-4215F-S0024** is captured as an editable KiCad 10.0.6 schematic and routed, two-layer PCB. It carries only the encoder, a **JST B4B-XH-A(LF)(SN)** four-way header and two non-plated mounting holes. The carrier's three 10 kΩ pullups and three 10 nF capacitors remain on the carrier; there are no duplicated filters or powered loads on this board. This is a fabrication candidate. Actual soldering, seating, thumbwheel force, connector service access and final assembly clearance still require qualification.

Native sources, Gerbers, routed plated-slot drill files, drill maps, ERC/DRC reports, a netlist, board/schematic SVGs and source/artifact hashes are in [pcb/encoder](pcb/encoder). Regenerate from the project root in PowerShell with:

```powershell
& .\.tools\kicad-10.0.6\bin\python.exe tools/build_encoder_board.py
```

Use the existing `tools/setup_kicad.ps1` runtime and CAD runtime. The generator requires the checked manufacturer reference `hardware/datasheets/PEC11H.pdf`; the download manifest restores that local reference. It checks the Bourns reference SHA-256 before building. The KiCad JST footprint is copied to the project library, so the saved board does not require a user's global footprint library. `.kicad_prl` is per-user UI state and is excluded from provenance.

## Wiring and placed pin coordinates

J1 mates with **JST XHP-4** and suitable genuine XH crimp contacts, for example **SXH-001T-P0.6** with the documented wire/insulation range. Read connector pin numbers from the native footprint and verify continuity. A cable viewed from its wire side can appear reversed; wire colours are not a pin-number reference.

| J1 pin | Net | Encoder terminal | Carrier endpoint |
| --- | --- | --- | --- |
| 1 | GND | C, S2 and both mounting-tab pads | J8 pin 1, GND |
| 2 | ENC_A | A | J8 pin 2, GP0 through existing carrier filter |
| 3 | ENC_B | B | J8 pin 3, GP1 through existing carrier filter |
| 4 | ENC_PUSH | S1 | J8 pin 4, GP2 through existing carrier filter |

The encoder and push switch are dry contacts. At 3.3 V with 10 kΩ pullups a closed channel carries about 0.33 mA, below the encoder's 10 mA contact rating. All three closed channels together draw about 0.99 mA through the carrier pullups. No supply rail is carried by J1. The grounded mounting pads are **not a substitute for the C terminal**. S1/S2 is a footprint convention for the two interchangeable SPST switch terminals.

The manufacturer shows the hole pattern looking toward the shaft/mounting face. The encoder is on **B.Cu**, which mirrors local X in the placed footprint. Board coordinates below are the KiCad top/F-side coordinate system: `u` increases right and `v` increases down. The generator asserts every electrical pad and both tab coordinates after the actual KiCad flip.

| Feature | Placed `(u,v)` mm | Global `(Y,Z)` mm |
| --- | --- | --- |
| Encoder shaft axis | (8.5, 12) | (3, -90) |
| A | (11, 19.5) | (5.5, -97.5) |
| C | (8.5, 19.5) | (3, -97.5) |
| B | (6, 19.5) | (0.5, -97.5) |
| S1, push signal | (11, 5) | (5.5, -83) |
| S2, push common | (6, 5) | (0.5, -83) |
| Mounting tabs | (2.1,12), (14.9,12) | (-3.4,-90), (9.4,-90) |
| J1 pins 1–4 | (21.5,8.25), (21.5,10.75), (21.5,13.25), (21.5,15.75) | (16,-86.25), (16,-88.75), (16,-91.25), (16,-93.75) |
| M2 mounting holes | (27.5,3.5), (27.5,20.5) | (22,-81.5), (22,-98.5) |

The five encoder electrical holes are Ø1.10 mm plated; its two grounded mounting tabs use **2.40 × 1.60 mm plated slots**. These are the upper ends of the Bourns mounting-hole ranges and are intentional prototype choices. The four JST holes are Ø0.95 mm plated, on 2.50 mm pitch. The two Ø2.40 mm M2 holes are non-plated. Confirm finished drill/slot tolerances with the fabricator and use the fabrication drill files, not the copper pad dimensions, as the hole specification. See the [Bourns mounting drawing and ratings](https://www.bourns.com/docs/product-datasheets/pec11h.pdf) and [JST XH header/mating drawing](https://www.jst-mfg.com/product/pdf/eng/eXH.pdf).

## CAD datums and component envelopes

The board is **29.5 × 24.0 × 1.6 mm**. Its global bounds are **X[-62.5,-60.9], Y[-5.5,24], Z[-102,-78]**. The encoder is on the X−62.5 face pointing toward −X. The connector is on the X−60.9 face pointing toward +X. Preserve the global encoder axis and M2 hole positions above; extend the earlier 24 mm board toward negative Y and move its encoder-side plane inward by 1 mm. Shorten the bracket's PCB supports so they seat on X−62.5. The main CAD owns the resulting screw engagement and shell/insertion checks.

Two exports have different purposes:

- `windflow-encoder-board-only.step` is KiCad's native export. Its actual bounds are **STEP X[0,29.5], Y[-24,0], Z[0,1.51]** because KiCad omits copper and solder mask in a board-only export. It is not the complete 1.6 mm assembly thickness.
- `windflow-encoder-mechanical-datum.step` is a re-imported, valid one-solid, **1.6 mm** drilled datum generated from the placed native pad positions and drills. Use this file for the PCB assembly envelope. It includes all 13 hole/slot locations but does not pretend to be a populated purchased-component model.

For either STEP coordinate system, the proper rigid transform is:

```text
global X = -62.5 + STEP z
global Y = -5.5 + STEP x
global Z = -78 + STEP y       (STEP y = -v)
```

Do not move the F-side component plane to X−60.99 because of the native 1.51 mm substrate. Component datums use the total board thickness. Do not apply the B-side mirror a second time after importing the board: the routed pad locations already include it.

The following envelopes are drawing reconstructions, not exact purchased CAD. Published dimensional tolerances still apply. The full assembly must model the solder-pin ends, connector withdrawal and wire bend separately.

| Item | Global X mm | Global Y mm | Global Z mm |
| --- | --- | --- | --- |
| Encoder main body, nominal 6.5 × 11.8 × 13.6 mm | -70 to -63.5 | -2.9 to 8.9 | -96.8 to -83.2 |
| Encoder rear-terminal tips, nominal | -60.5 tip | At pad positions above | At pad positions above |
| Bare JST header body, 7 mm high | -60.9 to -53.9 | 12.6 to 18.35 | -96.2 to -83.8 |
| Mated JST header/housing reserve, 9.8 mm high | -60.9 to -51.1 | 12.6 to 18.35 | -96.2 to -83.8 |
| JST solder-tail tips, nominal | -64.3 tip | 16 | At J1 pad positions above |

The connector reserve does not include wire insulation, the cable's bend radius, finger/gripper access or the axial withdrawal stroke. The nominal encoder rear body is X−63.5, leaving a **1.0 mm body-to-PCB gap**. With 3.0 mm terminals and a 1.6 mm PCB this gives about **0.4 mm protrusion** beyond the solder face. Actual terminal length, tab seating and solder fillet must be measured before ordering a final batch. The Bourns body has broad dimensional tolerances; do not assume these nominal numbers establish worst-case enclosure clearance.

## Assembly and inspection

1. Inspect finished board outline, Ø2.4 mm holes, plated round holes and plated slots. Check J1 pin 1 and footprint orientation against the tables above before fitting parts.
2. Fixture the encoder on B.Cu with its shaft toward −X and the body-to-board gap qualified from the actual part. Fit J1 on F.Cu. Preserve the gap without forcing pins or bending the encoder tabs to make an incompatible board fit.
3. Qualify soldering to the manufacturer's process: Bourns specifies wave soldering at **260 °C ±5 °C for 3 ±1 seconds** and does not recommend hand soldering. This design has not qualified a selective/wave or hobby soldering process. Inspect hole fill, fillets and insulation clearances after soldering.
4. With the cable disconnected, check J1 pin 1 to C and S2, pin 2 to A, pin 3 to B, and pin 4 to S1. Check no signal-to-signal short. Test the switch and quadrature state changes; A/B direction can subsequently be calibrated in firmware, but a wiring reversal must not be hidden by an unverified drawing.
5. Install the bracket's captive M2 nuts before placing the bracket in the shell. The panel bushing, nut and bracket carry the thumbwheel's axial press load; the PCB should be supported at both M2 holes without operating force carried through solder joints. Seat screw heads only on the mounting areas; avoid the copper exclusion zones. Final M2 screw length/engagement remains governed by the adopted main CAD.
6. Mate and strain-relieve the four-wire harness before closing the service tray. Verify it can be unplugged by gripping the housing. Route it clear of the wheel, servo linkages, tray-removal path and fan power wiring. Repeat a full turn, switch press and continuity test after enclosure installation.

## Verification scope

The generator exports and validates four functional nets against exact expected pin-node sets, 13 pads including two NPTH mounting holes, 27 route segments/vias and three rule areas. KiCad ERC and DRC run with all severities, explicit violation exit codes, all track checks and schematic/PCB parity. The final reports must have no violations, unconnected items or parity differences. The board uses 0.35 mm traces, 0.25 mm minimum clearance/edge clearance and one Ø0.60/0.30 mm via. There is no copper pour. The body-side rule area excludes foreign copper under the encoder; two mount rule areas reserve copper around screw locations.

`mechanical-validation.json` records actual native STEP bounds, all 13 transformed drills and the re-imported 1.6 mm datum's validity, solid count and analytical volume comparison. `provenance.json` records the generator, manufacturer reference and every generated artifact hash except itself and ignored `.kicad_prl` UI state. These checks establish the saved circuit/layout/datums; they do not prove enclosure assembly, solder process reliability, encoder feel or long-term use.

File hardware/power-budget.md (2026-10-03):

# USB-C power architecture and budget

Electrical revision E3, 2026-10-03. Selected contract: **USB PD 15 V / 2 A (30 W)**, supplied by the Raspberry Pi 45W USB-C Power Supply, UK Type G, white, with captive cable. Its 15 V / 3 A PDO supports this request. No rechargeable battery is needed for the stated desk use. The reserved top section of the IPS screen indicates system power/service/fault status. [Supply specifications](https://www.raspberrypi.com/products/45w-power-supply/).

| Load | Rail | Continuous design scenario | Electrical upper allowance |
|---|---:|---:|---:|
| Noctua NF-A12x25 G2 | 12 V | 0.15 A / 1.80 W at full PWM | 0.15 A / 1.80 W manufacturer maximum; validate startup pulse |
| Servo | 5 V dedicated | 0.25 A / 1.25 W moving/holding allowance | **1.00 A / 5.00 W** transient/jam allowance; above 0.6 A supplier measurement and 0.8 A family drawing |
| Adafruit 4311 IPS screen | 5 V logic | **0.100 A / 0.500 W** reserved even with dimmed backlight | **0.100 A / 0.500 W engineering allowance**, not a manufacturer maximum; measure the actual board |
| 8 ambient pixels | 5 V logic/LED | At 12/255 brightness, worst white 0.0226 A /0.113 W |0.480 A /2.400 W at unbounded full white |
| Pico, sensors and buffers | 5 V logic allocation |0.150 A /0.750 W |0.150 A /0.750 W conservative allocation; verify real firmware board current |
| **Total delivered to loads** | | **4.413 W** | **10.450 W** |
| Conversion, assuming only 85% aggregate efficiency | | **5.192 W input** | **12.294 W input** |
| PD/control/quiescent reserve | |0.20 W |0.20 W |
| Input eFuse, fuse and wiring reserve | |0.50 W |0.50 W |
| **Total input estimate** |15 V | **5.892 W /0.393 A** | **12.994 W /0.866 A** |

The E3 screen replaces the 16 main pixels and discrete RGB status lamp; the 8 downward ambient pixels remain. The upper allowance includes full-white ambient pixels and servo jam concurrently with full fan and screen. The 30 W contract leaves about **17.01 W /56.7% headroom**. EF1's approximately 1.49 A current limit remains a lower hardware ceiling; the 0.866 A estimate leaves about 0.54 A against a conservative 1.41 A low limit including resistor/tolerance allowance. These are engineering budgets, not measured efficiency or temperature results. A screen drawing more than its 100 mA allowance requires revising the budget before release.

REG2 carries worst 0.48 A ambient +0.10 A screen +0.15 A housekeeping = **0.73 A**, below the nominal 2.5 A family capability. The ambient TPS22810 carries only 0.48 A steady pixels. REG3 and its switch see 1.0 A allowance. REG1 sees 0.15 A. The screen and its CS/reset/backlight buffer are powered directly from REG2, allowing fault indication while SW3 shuts down decorative lighting. The new BUF2 backlight channel supplies about **3.79 mA /19.0 mW** with HIGH continuously asserted into R55=330 ohm, R56=1k and the onboard 10k pullup. That conservative DC load is included within the existing 150 mA /0.75 W Pico/sensor/buffer allocation, so it is not added again to the screen allowance. At the maximum allowed 80/255 PWM duty its HIGH-path average is about 6 mW before buffer switching/quiescent current, which also remains in that allocation. No display or LED power flows through GPIO. Use enough copper area and ventilation to maintain ratings in the closed base; Pololu's continuous rating is thermally dependent. [Regulator details](https://www.pololu.com/product/2858), [switch limits](https://www.ti.com/lit/ds/symlink/tps22810.pdf), [screen power and backlight interface](https://learn.adafruit.com/2-0-inch-320-x-240-color-ips-tft-display/pinouts).

At 85% efficiency, simultaneous upper loads imply approximately **1.84 W conversion heat**, plus the 0.5 W input-path allowance and smaller load-switch losses. Put TEMP1 near the REG2/REG3 hot region, thermally coupled to the board rather than measuring cold intake air. Vent the electronics base independently; the main fan cannot be assumed to cool the base after a stall. Screen backlight dimming reduces actual draw, but this budget conservatively reserves 100 mA in both columns.

## Commissioning measurements

Record input current at cold connection, open-nozzle full speed, fastest servo motion, jam cutoff, full-white ambient test, screen at maximum allowed backlight, and hot steady state. Use an oscilloscope at Pico VSYS, the servo connector and fan connector while exercising the linkage. Acceptance: no MCU brownout, no unexplained USB renegotiation, regulated fan voltage within 12 V nominal and below 13.2 V fan operating maximum, servo supply near 5 V, and PD input within 14–16 V during enabled operation. Verify fuse inrush coordination instead of raising fuse values after nuisance trips.

The firmware does not measure current directly. EF1 provides input current limiting and controlled startup; its IMON output is unused. Fuses, branch voltage monitoring, temperature and servo feedback provide further protection. EF1 in current-limit/latch mode can limit current before thermal shutdown; it is not an instantaneous disconnect at 1.49 A. Any regulator or switch that reaches its thermal shutdown during normal operation fails the enclosure thermal test.

## Capacitor inrush and sequencing

Each 470 uF output reservoir with TPS22810 CT=100 nF has estimated charging current `Cload × 46.62/Ct = 0.219 A`, using Ct in pF and consistent time units. The previous 10 nF value gave about 2.19 A before adding load current. The calculated full 5 V ramp is about 10.7 ms; firmware now waits 50 ms before pixel data. The theoretical ambient branch demand during charging plus a full-white load is about 0.70 A; use an oscilloscope to verify because load startup and CT tolerance are not ideal capacitors. [Switch slew model](https://www.ti.com/lit/ds/symlink/tps22810.pdf).

EF1 C29=100 nF gives approximately 12 ms initial 15 V ramp from TI's relation `t=8000×Vin×C`. Only C1=100 nF is added on the raw side; C2 and the regulator input capacitance are behind EF1. Sum actual module input capacitance and measure USB connection current rather than claiming USB compliance from this estimate. R39–41=330 ohm QOD resistors limit discharge heating; the output may take hundreds of milliseconds to discharge, so magnetic grille release still needs a fixed inner guard. [Input eFuse data](https://www.ti.com/lit/ds/symlink/tps2660.pdf).

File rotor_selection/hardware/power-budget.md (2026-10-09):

# USB-C power architecture and budget

**Rev B historical budget.** The active [Rev C calculation](../docs/rev-c-motor-power.md) requires 15 V / 3 A USB PD (45 W), revised protection and a capped ESC branch. The 2 A request and 12 V fan rail below are not the current motor architecture.

Electrical revision E3, 2026-10-03. Selected contract: **USB PD 15 V / 2 A (30 W)**, supplied by the Raspberry Pi 45W USB-C Power Supply, UK Type G, white, with captive cable. Its 15 V / 3 A PDO supports this request. No rechargeable battery is needed for the stated desk use. The reserved top section of the IPS screen indicates system power/service/fault status. [Supply specifications](https://www.raspberrypi.com/products/45w-power-supply/).

| Load | Rail | Continuous design scenario | Electrical upper allowance |
|---|---:|---:|---:|
| Noctua NF-A12x25 G2 | 12 V | 0.15 A / 1.80 W at full PWM | 0.15 A / 1.80 W manufacturer maximum; validate startup pulse |
| Servo | 5 V dedicated | 0.25 A / 1.25 W moving/holding allowance | **1.00 A / 5.00 W** transient/jam allowance; above 0.6 A supplier measurement and 0.8 A family drawing |
| Adafruit 4311 IPS screen | 5 V logic | **0.100 A / 0.500 W** reserved even with dimmed backlight | **0.100 A / 0.500 W engineering allowance**, not a manufacturer maximum; measure the actual board |
| 8 ambient pixels | 5 V logic/LED | At 12/255 brightness, worst white 0.0226 A /0.113 W |0.480 A /2.400 W at unbounded full white |
| Pico, sensors and buffers | 5 V logic allocation |0.150 A /0.750 W |0.150 A /0.750 W conservative allocation; verify real firmware board current |
| **Total delivered to loads** | | **4.413 W** | **10.450 W** |
| Conversion, assuming only 85% aggregate efficiency | | **5.192 W input** | **12.294 W input** |
| PD/control/quiescent reserve | |0.20 W |0.20 W |
| Input eFuse, fuse and wiring reserve | |0.50 W |0.50 W |
| **Total input estimate** |15 V | **5.892 W /0.393 A** | **12.994 W /0.866 A** |

The E3 screen replaces the 16 main pixels and discrete RGB status lamp; the 8 downward ambient pixels remain. The upper allowance includes full-white ambient pixels and servo jam concurrently with full fan and screen. The 30 W contract leaves about **17.01 W /56.7% headroom**. EF1's approximately 1.49 A current limit remains a lower hardware ceiling; the 0.866 A estimate leaves about 0.54 A against a conservative 1.41 A low limit including resistor/tolerance allowance. These are engineering budgets, not measured efficiency or temperature results. A screen drawing more than its 100 mA allowance requires revising the budget before release.

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

At 85% efficiency, simultaneous upper loads imply approximately **1.84 W conversion heat**, plus the 0.5 W input-path allowance and smaller load-switch losses. Put TEMP1 near the REG2/REG3 hot region, thermally coupled to the board rather than measuring cold intake air. Vent the electronics base independently; the main fan cannot be assumed to cool the base after a stall. Screen backlight dimming reduces actual draw, but this budget conservatively reserves 100 mA in both columns.

## Commissioning measurements

The5 October guard correction adds a nominal1.282 mA closed-contact path from unswitched5 V (6.41 mW), plus BUF4's at-most10 uA quiescent current and the33 uA GP15 pullup when LOW. These remain within the150 mA housekeeping allowance and are not added twice to the totals. Verify the contact load and buffer sequencing on the captured circuit before hardware operation; this analytical allowance is not a bench result.

Record input current at cold connection, open-nozzle full speed, fastest servo motion, jam cutoff, full-white ambient test, screen at maximum allowed backlight, and hot steady state. Use an oscilloscope at Pico VSYS, the servo connector and fan connector while exercising the linkage. Acceptance: no MCU brownout, no unexplained USB renegotiation, regulated fan voltage within 12 V nominal and below 13.2 V fan operating maximum, servo supply near 5 V, and PD input within 14–16 V during enabled operation. Verify fuse inrush coordination instead of raising fuse values after nuisance trips.

The firmware does not measure current directly. EF1 provides input current limiting and controlled startup; its IMON output is unused. Fuses, branch voltage monitoring, temperature and servo feedback provide further protection. EF1 in current-limit/latch mode can limit current before thermal shutdown; it is not an instantaneous disconnect at 1.49 A. Any regulator or switch that reaches its thermal shutdown during normal operation fails the enclosure thermal test.

## Capacitor inrush and sequencing

Each 470 uF output reservoir with TPS22810 CT=100 nF has estimated charging current `Cload × 46.62/Ct = 0.219 A`, using Ct in pF and consistent time units. The previous 10 nF value gave about 2.19 A before adding load current. The calculated full 5 V ramp is about 10.7 ms; firmware now waits 50 ms before pixel data. The theoretical ambient branch demand during charging plus a full-white load is about 0.70 A; use an oscilloscope to verify because load startup and CT tolerance are not ideal capacitors. [Switch slew model](https://www.ti.com/lit/ds/symlink/tps22810.pdf).

EF1 C29=100 nF gives approximately 12 ms initial 15 V ramp from TI's relation `t=8000×Vin×C`. Only C1=100 nF is added on the raw side; C2 and the regulator input capacitance are behind EF1. Sum actual module input capacitance and measure USB connection current rather than claiming USB compliance from this estimate. R39–41=330 ohm QOD resistors limit discharge heating; the output may take hundreds of milliseconds to discharge, so magnetic grille release still needs a fixed inner guard. [Input eFuse data](https://www.ti.com/lit/ds/symlink/tps2660.pdf).

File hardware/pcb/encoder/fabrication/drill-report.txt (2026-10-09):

Drill report for windflow-encoder.kicad_pcb
Created on 2026-10-05T17:53:45

Copper Layer Stackup:
    =============================================================
    L1 :  F.Cu                      front
    L2 :  B.Cu                      back

Drill file 'windflow-encoder-PTH.drl' contains
    plated through holes:
    =============================================================
    T1  0.300mm  0.0118"  (1 hole)
    T2  0.950mm  0.0374"  (4 holes))
    T3  1.100mm  0.0433"  (5 holes))
    T4  1.600mm  0.0630"  (2 holes)  (with 2 slots)

    Total plated holes count 12

Drill file 'windflow-encoder-NPTH.drl' contains
    unplated through holes:
    =============================================================
    T1  2.400mm  0.0945"  (2 holes))

    Total unplated holes count 2

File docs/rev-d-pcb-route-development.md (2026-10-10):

# Main PCB routing development

The captured 80 × 55 mm, four-layer circuit has a reproducible **connected routing candidate**. KiCad 10.0.6 reports zero clearance/fabrication violations, zero unconnected items and zero schematic-parity findings for this candidate, with `--severity-all --schematic-parity --exit-code-violations` and exit code 0. The authoritative placed board is still unrouted. Neither board is approved for manufacture.

The initial routing session, [session manifest](../hardware/pcb/rev_c/route-study/session-manifest.json) and [current candidate report](../hardware/pcb/rev_c/route-study/minimum-route-validation.json) preserve the design input and exact verification snapshot. [The reproducible candidate builder](../tools/build_rev_c_route_candidate.py) imports this checked session into an isolated working directory, verifies current footprint placement and pad nets, enforces the existing 0.2 mm minimum track width and moves five crowded bends. It changes 226 track widths and 22 incident endpoints, including the connected via at the UART bend. The fabrication rules, circuit and pads are unchanged.

Run the builder with the pinned KiCad Python at `.tools/kicad-10.0.6/bin/python.exe`. It writes the candidate under `build/rev-c-board/minimum-route-candidate`, then runs the pinned native KiCad checker. It does not write Gerbers or replace the authoritative board. Generated KiCad identifiers can differ on regeneration; always use the fresh report for the regenerated artifact.

## Why this is not the power-board release

Several power nets, including the protected 15 V bus, ESC feed, servo rail and logic supply, contain long 0.2 mm tracks. The current requirement includes a 3 A input and larger servo transients. Connectivity and clearance do not demonstrate that these tracks can carry those currents with acceptable drop and temperature. Treating the native routing pass as power qualification would be incorrect.

A separate initial route with wider power classes avoids geometric violations but still has 123 unconnected findings. Its missing connections include ground-plane access and the fine-pitch power-device pad escapes. It has not been adopted. Wide tracks cannot simply start at every fine-pitch pad; short reviewed necks, parallel copper and appropriate vias must connect those devices to adequately sized power and return copper.

The next PCB work is to redesign the power routes and returns, check regulator/eFuse/FET decoupling loops and heat spreading, finish the remaining connections, and rerun native checks at all severities. Record any deliberate short pad necks, their current allocation and their surrounding copper. Then review actual voltage drop, dissipation, stackup and component thermal limits before adopting the routed board and populated CAD. Physical voltage/inrush/load/thermal/EMC tests remain necessary after this design review.

The encoder daughterboard's separate native route checks remain distinct from this main-board candidate. This milestone does not change firmware motion inhibition or qualify the printed rotor.

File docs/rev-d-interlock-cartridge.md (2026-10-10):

# Rev D front-service interlock cartridge — development

The 150 mm grille interlock now has a checked front-removal design. This replaces the earlier independent bracket/raceway arrangement for the next main-stage integration. The current online 65-instance assembly has not yet adopted this cartridge. The fixed inner finger guard stays installed when either the cleaning grille or the cartridge is removed.

The cartridge contains the Omron D2F-01L drawing-reference switch, an adjustable switch bracket, a short covered wire raceway and a separate TPU liner/clamp. Two front-facing M2 screws secure the cartridge to heat-set inserts in the left flowing shell. The internal screws are assembled and adjusted with the cartridge outside the enclosure. Their approach directions, recessed nuts and head clearances allow the complete module to withdraw past the fixed guard.

## Checked geometry

- The standalone candidate passes **4,008 nominal part comparisons**. Two insert/shell contacts are explicitly bounded thermal-insertion interfaces; each occupies about 1.142 mm³ within its declared seat. A 2.166 mm³ contact between an ideal screw cylinder and a vendor female-thread solid is also bounded within the threaded seat. They are not waived external collisions.
- **196,561 sampled comparisons** pass for boost, encoder rotation/press, display service, grille removal, 70 mm front cartridge withdrawal, switch adjustment and declared tool approaches. No unintended overlap exceeds 0.0001 mm³ in these motion checks.
- All six separately printed cartridge meshes and the insert-seat coupon are watertight, consistently wound and single components.
- The two selected Alpha Wire 5853 signal wires have a nominal 1.1 mm envelope. Across nine switch adjustment positions from −2 to +2 mm, the smallest sampled centerline bend radius is **12.280 mm**. The selected wire's largest documented OD requires 10.922 mm at its specified 10×OD bend radius. These routes end at the cartridge exit; they do not establish a connected route to J12.

These results belong to the exact hashes in [cartridge-validation.json](../cad/rev_d/interlock-cartridge/cartridge-validation.json) and [service-motion-validation.json](../cad/rev_d/interlock-cartridge/service-motion-validation.json). The reports also identify the main-stage baseline and tool sizes. They do not establish tolerance extremes, switch trip/overtravel, conductor termination, strain-relief grip or safe rotor operation.

## Purchased parts for this module

| Item | Quantity | Geometry and function |
|---|---:|---|
| Omron D2F-01L | 1 | Primary drawing case/lever/terminal references; gold-contact COM/NO guard circuit, not a manufacturer solid or elastic model |
| ruthex RX-M2x4 | 2 | Manufacturer CAD, 3.6 mm outer diameter and 4 mm length; front cartridge seats |
| ISO 4762 M2×6, A2-70 | 2 | Adjustable bracket screws |
| ISO 4762 M2×10, A2-70 | 2 | Switch case screws |
| ISO 4762 M2×14, A2-70 | 4 | Wire clamp and raceway screws, outboard insertion direction |
| ISO 4762 M2×8, A2-70 | 2 | Front cartridge screws |
| ISO 4032 M2, A2 | 8 | Recessed captive nuts for the internal screws |
| ISO 7089 M2, A2 | 10 | Modelled 5 mm OD, 2.2 mm ID and 0.3 mm thickness; confirm the actual supplied washers |
| Alpha Wire 5853 | 2 signal conductors | About 73.7 and 79.0 mm modelled terminal-to-exit lengths at the nominal adjustment, plus termination allowance and the still-undesigned main loom |

The final project BOM must include these quantities when the cartridge is adopted. The wire tails and J12 connector length must be reconciled with the installed main board. Insulate the unused NC terminal.

The [ruthex primary product and CAD](https://www.ruthex.de/en/products/ruthex-gewindeeinsatz-m2-70-stuck-rx-m2x4-messing-gewindebuchsen) and [RX-series drawing](https://www.igo3d.com/mediafiles/Sonstiges/Ruthex/ruthex_Datenblatt_RX-Serie.pdf) specify the insert. The design uses a 3.2 mm printing bore, 5 mm blind depth and at least 1.4 mm radial plastic. The [Alpha Wire 5853 specification](https://www.alphawire.com/en/products/wire/hook-up-wire/premium/5853) governs the wire diameter and bend-radius check. Captured source files and download entries are retained in the project manifest.

## Assembly and service

1. Print the small insert-seat coupon before the whole head. Check the selected material, bore and actual insertion tool against the manufacturer insert and screw. Avoid bottoming a screw in the insert.
2. Install the two inserts from the front before fitting the cartridge. The checked insertion envelope is 5 mm diameter; confirm the actual tool fits.
3. Outside the head, fit the switch and adjustable bracket, terminate/insulate its wires, install the TPU liner, clamp and covered raceway. Confirm free lever motion before tightening the adjustment screws.
4. Insert the cartridge from the front, secure its two M2×8 screws and connect J12 through the bottom service opening. Then install the magnetic seat/keeper and cleaning grille. Perform electrical continuity and physical trip/overtravel tests before any motion qualification.
5. For cartridge service, disconnect USB power, remove the cleaning grille and magnetic seat/keeper, unplug J12 through bottom access, remove the two front screws and withdraw the entire cartridge approximately 70 mm. The permanent inner guard stays installed. Do not pull a still-connected loom.

The raceway has approximately 0.2 mm nominal clearance to the guard edge, and its clamp about 0.3 mm. These tight local fits require a cartridge/guard coupon and process compensation before the design can be released for printing. The geometric path pass is not a claim that an arbitrary FDM printer will reproduce it. The TPU mesh represents its installed shape; its free printed interference and grip must be tuned separately.

## Remaining work

Adopt the cartridge into the main-stage sources, regenerate the whole-stage static/mesh/motion/exchange reports and publish a fresh Onshape assembly/checkpoint. Then finish the connected main loom and connector restraint. Verify actual switch trip, post-trip overtravel, release on grille removal, insert pullout, fastener retention, tolerance extremes and dexterity on hardware. The existing motion-inhibited firmware and unqualified printed-rotor status remain in force.

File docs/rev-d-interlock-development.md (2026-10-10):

# Rev D grille interlock development

The independent adaptation in `cad/rev_d_interlock.py` passed **1,233 nominal part comparisons with zero collisions** and exit code zero against the source-matched 65-group stage. It remains a separate pilot in `cad/rev_d/interlock-study`; it is **not** included in the current main assembly or Onshape version.

The selected switch is **Omron D2F-01L**, with a low-level contact. COM and NO follow the current electrical wiring; NC stays insulated. The case, lever and three terminals are drawing envelopes. They do not simulate the snap action, spring return, contact timing or elastic overtravel. The integral grille tongue has 4 mm nominal root embed. The intended adjustment is ±2 mm along airflow, with 0.25 mm nominal post-trip travel and 0.20 mm additional stop travel, below the drawing's 0.55 mm minimum overtravel. Those inputs require actual switch calibration before use.

The switch case center is (−60.2, 255.05, 18.4) mm. Its front actuator contact datum is Y = 259.85 mm, outside the useful outlet. The revised lower raceway anchor stays at least 0.3 mm outboard of the 104 mm panel width, while connecting to the rounded duct corner. A broader first anchor touched the open lower panel; that interference was corrected geometrically rather than excluded from checking. The protective cover ends behind the fixed grille seat and has an open lower inboard access window. All printed pilot parts must remain single connected solids.

The two insulated signal routes use a 1.1 mm envelope, separate 1.2 mm liner holes and a 14 mm bend input. The sampled minimum centerline radius is approximately 13.91 mm. The selected [Alpha Wire 5853 specification](https://www.alphawire.com/en/products/wire/hook-up-wire/premium/5853) gives 0.039 ± 0.004 inch outside diameter and a minimum bend radius of ten times outside diameter. At the maximum stated diameter, that is 10.922 mm. The route begins beyond each terminal tip; bare solder bonds, connector transitions, complete main-harness routing and service slack are not modeled by this pilot.

Reproduce with the pinned CAD environment using `cad/rev_d_interlock.py`, then `tools/verify_rev_d_interlock_mesh.py`. The nominal report records every source and STEP hash. Mesh checks apply only to the six isolated printed bracket, cover, clamp, raceway, lid and TPU liner outputs.

The next authorized work is to check grille withdrawal, bracket adjustment, boost motion, wheel press and screen service against these changes, then resolve the screw/nut stacks and driver approaches. In particular, a straight side approach to the present X-axis bracket screws would meet the outer enclosure; service access must be redesigned or verified with a concrete tool path. This is unfinished mechanical work, not a claim that a future physical test alone will solve access. Changed head/grille geometry needs fresh complete stage, mesh, motion and export reports before integration online.

Physical checks remain switch travel/return, contact debounce and hardwired inhibit, wire/liner grip, strain relief, repeated grille removal, magnet retention and residual rotor coast. The fixed printed finger guard is not qualified fragment containment for the experimental rotor.

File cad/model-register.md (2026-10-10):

# Purchased CAD register

Manufacturer files are in `vendor/`; download URLs and SHA-256 hashes are in `../hardware/sources.json`. `vendor-checks.json` records eight loaded, valid manufacturer B-reps, including the screen. **Rev D is the current 150 mm CAD candidate**, using these purchased references, a new printed rotor and a compact hollow enclosure. See `../docs/rev-d-150mm-cad.md` and `rev_d/stage-validation.json` for the current geometry and limitations; `onshape-rev-d-checkpoint.json` records online integration when verified. The editable native rotor is a separate profile study from the independently checked P2 fit article.

The new `WindflowRevDHead.fs` native airpath has 17 parameters and passes both open and maximum-closure evaluations with a seven-body assertion. Its source is saved and readback-verified in the current Onshape document's Feature Studio `fcaf5b7ea81e608e05d9abb6`. The main-workspace Part Studio `399cdd4584e017c0a30623b4` visibly contains seven parts in default-open mode; `rev_d/native-airpath-validation.json` and the saved Onshape screenshot record it. It is distinct from the detailed local split-shell fit article.

The current detailed [Rev D assembly](https://cad.onshape.com/documents/5ca1b5b26cd9a4a93dde4737/w/6d3d38529391b53ad011b362/e/57c900ab51f3a2c24ffaefca) visibly contains **65 top-level instances**, including the retained side-facing HUSB238 board and its four ideal fastener envelopes. The local exchange round-trip contains 165 solids. The imported hierarchy retains purchased sub-bodies in their own Part Studios/subassemblies; these are not native motion mates. Whole-assembly native interference returned six contacts solely within the downloaded HUSB238 reference, and no custom-part findings. `onshape-rev-d-checkpoint.json` records the exact source and immutable version `9e2e00efc42a6cb0a410eb64`. Independent later pilots are not included in that checkpoint.

The 76-instance Rev B assembly dated 2026-10-03 and 71-instance Rev C import are historical checkpoints, recorded in `onshape-inspection.md` and `onshape-rev-c-checkpoint.json`. Their reports cannot qualify new Rev D geometry, current wiring, physical fit or operation. Earlier faulty Rev B housings were repaired and checked for their own source snapshot. Native mates, all fasteners, PCB population, connected looms, pressure plumbing and the revised grille interlock remain unfinished integration.

| Component | Exact source/model | Measured bounding box, mm | Design allowance and discrepancy |
|---|---|---|---|
| T-Motor Pacer V4 P2406 Juicy 2060 KV | Manufacturer dimensions; drawing envelope, no verified exact STEP | 30.2 diameter × 31 overall reference; current shoulder/shaft assumptions separately identified | Four M3 holes on Ø16 mm pitch circle. Prop-seat/shaft projection, thread pitch and screw depth must be measured before rotor retention or operation. |
| Team Triforce A50S V2.3c | Published ESC family information; unverified drawing envelope | 46 × 22 × 17 reference envelope | Exact board/case, connectors and mounting datums still require measured confirmation. This is not manufacturer CAD. |
| NF-A12x25 G2 PWM | Noctua public CAD | 120 x 120 x 27 | Includes silicone pads. Bare frame is 25 deep. Reserve at least 120.6 x 120.6 x 27.6 before additional isolators. Mounting centres 105 square from manufacturer specs. Public impeller is modified; **do not use it for CFD**. |
| Raspberry Pi Pico SC0915 | Raspberry Pi Pico-R3 | 21 x 3.73 x 52.3, in vendor axes | Board is 51 x 21; micro-USB overhang makes full envelope longer. Add pin/header and cable volumes separately. |
| Adafruit HUSB238 #5807 | Adafruit CAD | 20.32 x 24.608 x 12.10 | Includes terminal block and pins; reserve 21 x 26 x 14 plus C-plug insertion, cable bend and screw access. |
| D24V22Fx regulator family | Pololu family STEP | 17.78 x 17.78 x 8.219 | Published board 17.8 square, nominal height 8.0; use 9.0 height allowance. Both mounting holes 2.18, centres 13.2 square diagonally. Family model covers #2855 and #2858. |
| Adafruit #1426 NeoPixel stick | Adafruit CAD | 50.8 x 10.16 x 2.6 | Product page specifies 51.10 x 10.22 x 3.19. **Use the larger product dimensions**, with channel 51.6 x 10.8 x 3.7 minimum. Measure current supplied board revision. |
| Adafruit MCP9808 #1782 | Adafruit CAD | 20.32 x 12.7 x 3.07 | The selected 1782 is the original non-STEMMA product. [Manufacturer revision history](https://www.adafruit.com/product/1782) confirms the 2023 change was silkscreen only; 5027 is the larger STEMMA product. Mount axes (2.54,10.16) and (17.78,10.16), diameter 2.5 mm. Allow 21.6 x 13.6 x 3.7 and confirm actual sample/pigtail clearance. |
| Sensirion SDP810-125Pa | Sensirion SDP810 STEP | 29 x 27.05 x 17.95, in vendor axes | Matches published 29 x 18 x 27.05. Pins have **2 mm pitch** and short projection; direct-soldered daughterboard with independent housing and PCB support replaces the incompatible original socket. The pressure board and matched tubing route are being integrated locally; solder-tail strain relief, sealed fit and flow response still need qualification. |
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

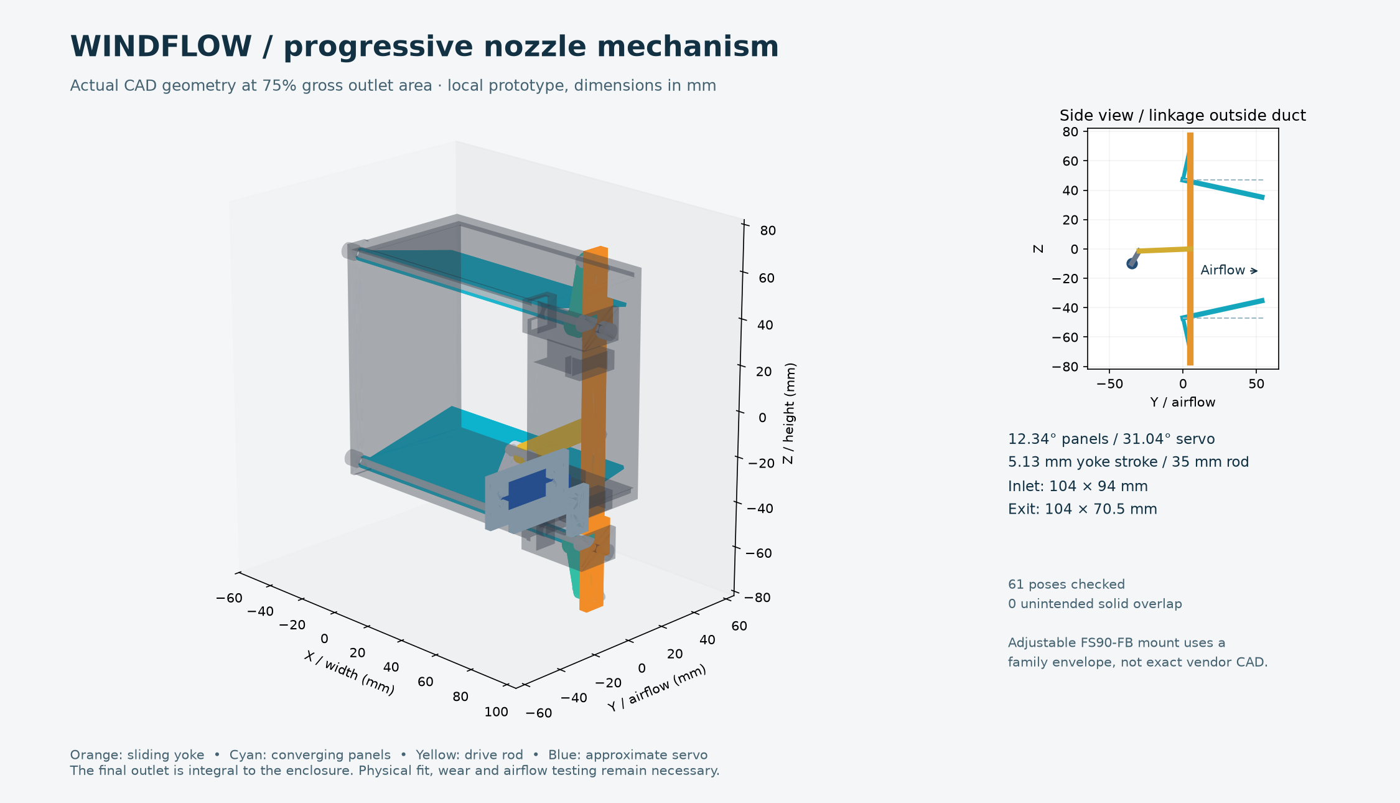
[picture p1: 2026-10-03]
cad/prototypes/overview.png

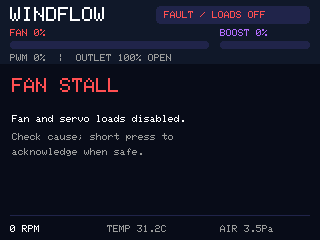
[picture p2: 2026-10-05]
docs/images/fault.png

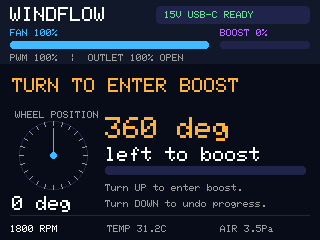
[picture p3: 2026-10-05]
docs/images/entry-start.png

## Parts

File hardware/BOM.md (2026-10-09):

# Windflow prototype BOM — selected architecture, not an enclosure release

**Rev B historical BOM.** The active 6 October 2026 motor redesign is [Rev C](../docs/rev-c-motor-power.md), with its [exact changed-component BOM](rev_c/BOM-fragment.csv). The Noctua fan, 12 V fan regulator, PWM/tach circuit and former fan load switch below must not be used for the P2406/ESC build. Retained screen, encoder, servo and ambient parts remain subject to Rev C power and fit verification.

Updated 2026-10-05, electrical revision E3 with the grille-contact buffer correction. Quantities of mounting hardware remain provisional until the final CAD fastener schedule is frozen. Manufacturer ratings and engineering allowances are distinguished below. No components have been purchased. The E3 screen/control revision replaces the two main sticks and discrete RGB status lamp. The downward ambient stick remains. The electrical population below is selected for the documented prototype netlist; a **90 x 65 x 22 mm carrier allowance is not a finished PCB**. The passive encoder P1 board is routed and independently checked; main-carrier capture and pressure-board integration are in progress. See [circuit review](circuit-review.md) and [electronics assembly](../docs/electronics-assembly.md).

## Major electrical and electromechanical components

| Ref / qty | Manufacturer / exact model | Function, interface and supply | Size / current / selection reason |
|---|---|---|---|
| FAN1 / 1 | **Noctua NF-A12x25 G2 PWM**, EAN 9010018100686 | 12 V, four-wire, 25 kHz PWM, two tach pulses/rev | 120 x 120 x 25 bare, 27 mm with pads; 105 mm mounting pitch. Max 0.15 A / 1.8 W, 1800 rpm, 107.3 m³/h free delivery, 3.14 mmH2O shutoff; these endpoints are not simultaneous. Quiet, pressure-capable, continuous duty. [Manufacturer](https://www.noctua.at/en/products/nf-a12x25-g2-pwm/specifications). |
| MCU1 / 1 | **Raspberry Pi Pico SC0915**, RP2040, unheadered | 3.3 V GPIO; VSYS from 5 V via SS14; native USB service, I2C, ADC, PWM/PIO | PCB 51 x 21; full CAD 52.3 long with USB overhang. Allocate 0.15 A at 5 V to MCU plus sensors/buffers, not a claimed maximum board rating. Hardware-timed fan/servo and ambient output, SPI screen. [Documentation](https://www.raspberrypi.com/documentation/microcontrollers/pico-series.html). |
| SERVO1 / 1 | **FEETECH FS90-FB**, **Pololu 3436** | 5 V regulated; 50 Hz RC PWM plus analog position feedback fourth wire | Case 23.2 x 12.5 x 22; family drawing 32.6 overall lug span, 27 lug centres, 27.3 body-to-spline top, horn extra. 1.3 kgf-cm at 4.8 V; Pololu measured 0.6 A stalled at 6 V, related family drawing lists 0.8 A: budget **1.0 A** including uncertainty/transient. Feedback permits jam detection. Backorder shown during research; source exact FB variant before mount release. [Supplier specification](https://www.pololu.com/product/3436/specs). |
| ENC1 / 1 | **Bourns PEC11H-4215F-S0024** | Passive quadrature contacts, 24 pulses / 24 detents, momentary push | 11.8 mm body width, 6 mm D-shaft, 15 mm from mounting face, M7 x 0.75 bushing. Contact limit 10 mA / 5 V; use 3.3 V / 10k pullups. High detent force, nominal 0.0206 Nm and 100k rotations; switch force nominal about 6 N means a well-supported wheel and stable base are required. [Datasheet](https://www.bourns.com/docs/product-datasheets/pec11h.pdf). |
| DISP1 / 1 | **Adafruit 4311**, 2.0 inch **ST7789 EYESPI IPS TFT** | 5 V VIN; 3.3 V SPI control via onboard level conversion, separate PWM backlight input; 320 x 240 pixels in landscape | Manufacturer product-page size 59.2 x35.5 x3.7 mm; downloaded 15-solid vendor assembly actually 59.055 x35.56 x6.0809 mm including rear components. Reserve 6.1 mm minimum before connector/harness space; the 2023 EYESPI revision keeps outline/pinout but its rear connector needs a physical fit check. Reserve **0.10 A / 0.50 W** at 5 V as an engineering allowance, not a published maximum. Top 64 rows replace speed/boost and power/status bars; lower area shows the relative encoder dial and remaining entry turn. [Product and revision dimensions](https://www.adafruit.com/product/4311), [pinouts](https://learn.adafruit.com/2-0-inch-320-x-240-color-ips-tft-display/pinouts), [manufacturer CAD](https://learn.adafruit.com/2-0-inch-320-x-240-color-ips-tft-display/downloads). |
| LED3 / 1 | **Adafruit 1426 NeoPixel Stick**, 8 RGB pixels | 5 V, 800 kHz GRB addressable; downward ambient only | Design for 51.10 x 10.22 x 3.19; CAD is smaller. Budget 60 mA per pixel = 0.48 A full white; normal brightness is much lower. Current lot may be WS2812B/SK6812 compatible. [Product](https://www.adafruit.com/product/1426). |
| TEMP1, 2 / 2 | **Adafruit 1782 MCP9808 breakout**, Microchip MCP9808 | 3.3 V I2C, 0x18 / 0x19 (A0 high on second) | Non-STEMMA board, manufacturer rounded size 21 x 13 x 2; CAD 20.32 x 12.7 x 3.07. Two 2.5 mm holes, 15.24 mm pitch. Reserve 21.6 x 13.6 x 3.7. Manufacturer says the 2023 revision changed silkscreen only; product 5027 is the different STEMMA board. Chip roughly 0.2 mA typical active; allocate 1 mA each. Sense regulator region and base air; characterize lag. [Product and revision history](https://www.adafruit.com/product/1782). |
| DP1 / 1 | **Sensirion SDP810-125Pa**, order **1-101597-01** | 3.3 V, I2C 0x25; two pressure tubes | 29 x 18 x 27.05, maximum 5.5 mA. +/-125 Pa, low-pressure resolution suited to a 31 Pa fan. Adds meaningful restriction sensing because regulated RPM is not airflow. [Manufacturer](https://sensirion.com/products/catalog/SDP810-125Pa). |
| PD1 / 1 | **Adafruit 5807 HUSB238 USB-C PD sink** | Configure jumpers **15 V / 2 A**; I2C 0x08 reports contract | PCB/USB about 24.6 x 20.3; supplied terminal block reaches 12.1 mm overall height in CAD. Request fixed PDO; verify measured bus and negotiated current before enabling loads. [Guide](https://learn.adafruit.com/adafruit-husb238-usb-type-c-power-delivery-breakout/pinouts). |
| REG1 / 1 | **Pololu D24V22F12 #2855** | 15 V to 12 V fan rail; PG to MCU | 17.8 square, allow 9 high. Typical max 2.2 A at stated test conditions; our load is 0.15 A. Fixed voltage avoids accidental fan overvoltage. [Product](https://www.pololu.com/product/2855). |
| REG2, 3 / 2 | **Pololu D24V22F5 #2858** | REG2 5 V logic/LED; REG3 separate 5 V servo | Same footprint, nominal max 2.5 A; REG2 worst 0.73 A including display/ambient/logic, REG3 1.0 A allowance. Check hot-enclosure derating. 5.3–36 V input for the 5 V version; output requires dropout headroom. [Product](https://www.pololu.com/product/2858). |
| SW1–3 / 3 | **Texas Instruments TPS22810DBVR** | High-side load disconnect on fan 12 V, servo 5 V, cosmetic LED 5 V | SOT23-6; 2.7–18 V operating, 2 A DBV continuous subject to thermal layout. 3.3 V enable, 100k pulldown; defaults off. Thermal shutdown is not a precision current limiter. [Datasheet](https://www.ti.com/lit/ds/symlink/tps22810.pdf). |
| BUF1, 2 / 2 | **Nexperia 74AHCT125D,118** | BUF1 ambient data on switched LED rail; BUF2 display CS/reset/backlight on logic rail | SO14, 8.65 x 3.9 body, 6 mm lead span. TTL inputs, specified input leakage with VCC=0. Three noninverting display channels preserve PWM polarity; BL uses channel 3. Do not substitute generic HC/AHC buffers. [Datasheet](https://assets.nexperia.com/documents/data-sheet/74AHC_AHCT125.pdf). |
| BUF3 / 1 | **Nexperia 74AHCT1G125GW,125** | Noninverting GP8 servo buffer, powered from **switched servo 5 V** | TSSOP5/SOT353-1, 2 x 1.25 mm body. Removes the always-powered signal path into an unpowered servo. [Manufacturer](https://www.nexperia.com/products/analog-logic-ics/logic/buffers-inverters-transceivers/buffers/74AHCT1G125GW.html). |
| BUF4 / 1 | **Texas Instruments SN74LVC1G17DBVR** | Noninverting Schmitt buffer, VCC3.3 V; 5 V grille contact input to GP15 | SOT23-5, body2.9 x1.6 mm. 5.5 V tolerant input and Ioff protection; permits the gold contact's nominal5 V /1.28 mA load without applying5 V to the Pico. Maximum quiescent10 uA. [Manufacturer datasheet](https://www.ti.com/lit/ds/symlink/sn74lvc1g17.pdf) |
| ISO1 / 1 | **Texas Instruments TMUX1511PWR** | Three ADC signal isolators; fourth channel unused | TSSOP14, 5 x 4.4 mm body; 3.3 V, up to 70 uA supply. Powered-off protection covers the divided signals. [Datasheet](https://www.ti.com/lit/ds/symlink/tmux1511.pdf). |
| SUP1 / 1 | **Texas Instruments TPS3808G33DBVR** | Holds ADC isolation off until 3.3 V is healthy | SOT23-6, 2.9 x 1.6 mm body; 3.07 V nominal threshold, CT open gives 20 ms nominal release delay. No extra GPIO. [Datasheet](https://www.ti.com/lit/ds/symlink/tps3808.pdf). |
| EF1 / 1 | **Texas Instruments TPS26600PWPR** | Input inrush control, current limiting, OVP and reverse-current blocking before the regulator bank | HTSSOP16 with thermal pad, 5 x 4.4 mm body; 4.2–60 V input, 150 milliohm typical. Netlist sets about 1.49 A limit and 16.66 V OVP. Requires a soldered thermal pad and PCB copper. [Datasheet](https://www.ti.com/lit/ds/symlink/tps2660.pdf). |
| PSU1 / 1 | **Raspberry Pi 45W USB-C Power Supply, UK Type G, white** | External supply; captive 1.5 m USB-C cable, 15 V / 3 A PDO available; device requests 2 A | Approximately 56 x 52 x 36 mm body excluding plug. Exact regional/color model is specified; confirm distributor SKU at order. The 27 W version has only 15 V / 1.8 A and is unsuitable for this configured 2 A request. [Manufacturer](https://www.raspberrypi.com/products/45w-power-supply/). |
| Q1 / 1 | **Nexperia 2N7002,215** | Open-drain inverter between fan PWM pin and ground | SOT23, 60 V VDS; PWM input only, not motor supply. Fan input sources at most 5 mA. Gate 100 ohm series and 100k pulldown. [Manufacturer](https://www.nexperia.com/product/2N7002). |
| GUARD1 / 1 | **Omron D2F-01L** | Guard-present SPDT switch; use COM/NO so installed guard closes to ground | Body approximately 12.8 x 5.8 x 6.5 plus lever and pins; mounting per drawing. Low-level gold contacts. Removable grille interruption stops loads; fixed inner guard still required. [Datasheet](https://components.omron.com/sites/default/files/datasheet_pdf/B036-E1.pdf). |

## Power protection, connectors and passives

All resistors are 1%, unless noted. Quantities are populated quantities, not reel purchase quantities. Breakout-board onboard passives are included with those products and are not counted again. Reference designators are defined in [wiring.md](wiring.md). Do not fabricate from this BOM alone; the carrier needs schematic capture, ERC, layout and DRC.

| Ref / quantity | Exact manufacturer part | Value / use |
|---|---|---|
| F1 / 1 | Littelfuse **0451002.MRL** | 2 A input fuse, before EF1 |
| F2 / 1 | Littelfuse **0451.500MRL** | 0.5 A fan branch fuse; corrected order code |
| F3 / 1 | Littelfuse **0451001.MRL** | 1 A servo branch fuse |
| D1 / 1 | Littelfuse **SMBJ18A** | Input TVS, cathode fused raw PD+, anode GND; transient suppression, not DC voltage regulation |
| D2 / 1 | Vishay **SS14-E3/61T** | REG2 anode to Pico VSYS cathode; service-USB isolation |
| C2,C6–8 / 4 | Panasonic **EEU-FR1E101** | 100 uF / 25 V: protected input bus and three regulator outputs |
| C9,C10 / 2 | Panasonic **EEU-FR1A471** | 470 uF / 10 V: switched servo and cosmetic LEDs |
| C3–5,C11–13 / 6 | Murata **GRM188R71E105KA12D** | 1 uF / 25 V X7R 0603: three regulator inputs, three load-switch inputs; check effective capacitance at DC bias |
| C1,C14–25,C29,C31 / 15 | Murata **GRM188R71H104KA93D** | 100 nF / 50 V X7R 0603: raw input, switch CT, buffers, isolator, supervisor, pressure connector, ADC filters, EF1 slew; C31 is BUF4 decoupling |
| C26–28,C32 / 4 | Murata **GRM188R71C103KA01D** | 10 nF / 16 V X7R 0603: encoder A/B/push and guard-contact filter |
| R10–12,R14,R19,R23–24,R28,R31–32,R34–35,R38,R44,R59–60 / 16 | Yageo **RC0603FR-07100KL** | 100k: pulldowns, dividers and EF1 UVLO; R59 holds the GPIO-side BL buffer input low during reset, R60 pulls GP15 high |
| R1–3,R29,R37,R47,R57–58 / 8 | Yageo **RC0603FR-0710KL** | 10k: encoder/display CS/reset pullups, bus lower divider, supervisor pullup, EF1 OVP lower |
| R4,R8–9 / 3 | Yageo **RC0603FR-074K7L** | 4.7k: tach and two PG pullups |
| R5 / 1 | Yageo **RC0603FR-073K9L** | 3.9k: guard contact pullup to unswitched5 V, feeds BUF4 input; not a Pico pullup |
| R6–7 / 0 fitted, 2 available | Yageo **RC0603FR-074K7L** | Optional I2C pullups; populate only after measuring combined breakout pullups |
| R30,R33,R36 / 3 | Yageo **RC0603FR-071ML** | 1M: ADC-side pulldowns after ISO1 |
| R13 / 1 | Yageo **RC0603FR-07100RL** | 100 ohm: fan PWM gate |
| R16–17,R55 / 3 | Yageo **RC0603FR-07330RL** | 330 ohm: ambient data, servo PWM and display backlight series |
| R50–54 / 5 | Yageo **RC0603FR-0733RL** | 33 ohm series: TFT MOSI, SCK, buffered CS, D/C and buffered RST; populate at driver ends |
| R56 / 1 | Yageo **RC0603FR-071KL** | 1k: TFT BL-to-GND at the display end; nominal 0.30 V against its onboard 10k pullup if the buffer/harness is disconnected. This replaces the earlier 2.2k value. |
| C30 / 1 | Murata **GRM188R71E105KA12D** | 1 uF / 25 V X7R at display VIN; additional to onboard decoupling |
| R39–41 / 3 | Yageo **RC1206FR-07330RL** | 330 ohm, 0.25 W, 1206: load-switch QOD resistors |
| R42 / 1 | Yageo **RC0603FR-078K06L** | 8.06k: EF1 current limit |
| R43 / 1 | Yageo **RC0603FR-07402KL** | 402k: EF1 current-limit/latch mode |
| R45 / 1 | Yageo **RC0603FR-0715KL** | 15k: EF1 UVLO lower |
| R46 / 1 | Yageo **RC0603FR-07130KL** | 130k: EF1 OVP upper |
| J1,J12 / 2 each | JST **B2B-XH-A(LF)(SN)** and **XHP-2** | PD power and guard harnesses |
| J2,J7 / 2 each | JST **B3B-XH-A(LF)(SN)** and **XHP-3** | PD I2C and ambient LEDs |
| J8–11 / 4 each | JST **B4B-XH-A(LF)(SN)** and **XHP-4** | Encoder, two temperature boards and pressure sensor |
| J6 / 1 each | JST **B8B-XH-A(LF)(SN)** and **XHP-8** | Display harness: VIN, GND, MOSI, SCK, CS, D/C, RST, BL |
| 34 installed; buy 40 | JST **SXH-001T-P0.6** | One crimp per XH housing cavity above; 22–28 AWG per JST tooling/specification |
| J3 / 1 | Molex **470531000** | Keyed four-pin fan header, preserves original fan connector; [drawing](https://www.molex.com/content/dam/molex/molex-dot-com/products/automated/en-us/salesdrawingpdf/470/47053/470531000_sd.pdf) |
| J4 / 1 | Samtec **TSW-103-07-G-S** | Servo's original three-pin plug; add printed retention and polarity marking |
| J5 / 1 | Samtec **TSW-101-07-G-S** | Servo's original single feedback socket; retain alongside J4 |
| J14 / 1 each | Samtec **TSW-102-07-G-S**, **SNT-100-BK-G** | Recessed service jumper |
| 3 | Samtec **SSW-105-02-G-S** | Regulator sockets; modules include male header; label all five nets |
| 2 each | Samtec **SSW-120-02-G-S**, **TSW-120-07-G-S** | Removable Pico socket/header rows |
| 4 each | Accu **SSCF-M1.6-10-A2** screws and **HPN-M1.6-A4** nuts | Pico tray mounting: DIN 912 / ISO 4762, 3 mm maximum cap-head diameter, 1.6 mm maximum head height, 1.5 mm hex drive. DIN 934 nuts 3.2 mm AF x1.3 mm. Replaces M2 Pico screws to leave room beside header insulators; no washers. Printed holes 1.8 mm, nut pockets 3.3 mm AF. [Screw specification](https://www.accu.co.uk/metric-cap-head-screws/3785-SSCF-M1-6-10-A2), [nut specification](https://www.accu.co.uk/hexagon-nuts/7901-HPN-M1-6-A4) |
| 1 fabricated | SDP810 daughterboard, **18 x 12 x 1.6 mm**, four 0.8 mm plated holes at **2 mm pitch** | Sensor soldered directly; two M2 PCB holes and independent housing screws take harness/tubing loads. The earlier 2.54 mm socket was incompatible. The reviewed 2 mm sockets also needed more insertion depth than the sensor's shortest allowed pins. |
| 2 matched lengths, finalized by the plumbing route | **Saint-Gobain Tygon E-3603 ACF00010** | 5/32 in ID (3.96875 mm), 9/32 in OD (7.14375 mm), 1/16 in wall; manufacturer minimum bend radius 12.7 mm. Sensirion recommends approximately 4 mm ID for SDP8xx. The earlier 2 mm-ID proposal was incompatible with the 5.2 +/-0.2 mm sensor barbs. Actual sealed fit, matched cut lengths and route are being checked in the plumbing study. [Tubing table](https://www.ics.saint-gobain.com/sites/hps-mac3-lifesciences-fluid-transfer/files/2022-11/tygon-e-3603-lab-application-tubing.pdf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), [SDP engineering guide](https://sensirion.com/en/media/documents/C3059EE6/667E9FD4/DP_AN_Engineering_Guide_V1.0.pdf) |
| 2 m power, 3 m signal initial | **Alpha Wire 3051** 22 AWG stranded for power; **Alpha Wire 5853** 26 AWG PTFE signal wire, nominal 0.99 mm OD (0.039 in ±0.004 in), 10× OD minimum bend radius | Use red/black for power and identifiable signal colours. The 5853 size fits the interlock trial raceway more credibly than the earlier generic 1.2 mm envelope; confirm the received insulation OD before cutting. [3051](https://www.alphawire.com/en/products/wire/hook-up-wire/premium/3051), [5853](https://www.alphawire.com/en/products/wire/hook-up-wire/premium/5853) |
| 1 fabricated set | Windflow E3 main carrier + encoder P1 daughterboard + SDP pressure daughterboard | FR4, plated through holes. Encoder P1 is routed and checked; main-carrier placement/routing and the pressure-board design are separate prototype work in progress. |

The above is the selected electrical population for E3; PCB capture and layout remain unfinished. It does not imply that every MPN is currently in stock. Use authorized distributors and confirm the orderable packaging suffix and board revision. The regional/color power-supply model is selected but its distributor-specific stock code remains to be recorded at purchase. Connector numbering is electrical, not a claim about an existing PCB silkscreen.

## Mechanical bought parts and printing materials

| Qty initial | Part | Use / limits |
|---|---|---|
| 8 | **K&J Magnetics D42**, N42 axial disc, 6.35 diameter x 3.175 mm | Four opposing pairs; 6.55 diameter x 3.40 mm test pockets. Vendor zero-gap pull force is not the assembled force through printed skins. [Product](https://www.kjmagnetics.com/d42-neodymium-disc-magnet). |
| 24 | **ruthex RX-M3x5.7** heat-set inserts | 5.7 long, manufacturer hole guidance plus test coupon. Initial 4.0 mm pilot / 6.8 mm depth must be confirmed with actual insert/material. [Product](https://www.ruthex.de/products/ruthex-gewindeeinsatz-m3-100-stuck-rx-m3x5-7-messing-gewindebuchsen). |
| 16 / 8 / 4 | **ISO 4762 A2-70 M3x8 / M3x12 / M3x35** socket head screws | Enclosure, carrier and fan mounts; final lengths selected after stack is measured, never bottom screws in inserts |
| 32 / 8 | **ISO 7089 A2 M3 washers / ISO 10511 A2 M3 nyloc nuts** | Mechanical joints and through-bolt mounting |
| 8 | **ISO 4762 A2-70 M2x8** + matching **ISO 4032 M2** nuts | Regulator boards and servo mounting, subject to actual lug hole verification |
| 2 | **Stainless steel ground rod, 3 mm diameter, cut to 155 mm**, deburred | Full-width boost-panel hinge shafts, installed X=-60.5..94.5 mm. Confirm sliding fit with bore coupon. |
| 4 | **Mädler 62300300**, DIN 705 A shaft collar, 3 mm bore, 7 mm OD, 5 mm width, supplied M2x3 set screw | One collar at each shaft end; accessible with linkage cover removed. |
| 2 | Stainless tube **7 mm OD / 3.3 mm ID**, cut to **7.6 mm** | Right-side hinge spacers, installed X=77.2..84.8 mm. Deburr square. |
| 4 | Stainless tube **3 mm OD / 2.1 mm ID**, cut **2 x 9.1 mm, 1 x 9.6 mm, 1 x 8.6 mm** | Crank/yoke, rod/yoke and horn/rod pivot sleeves; screws clamp the metal stacks, allowing printed parts to rotate. |
| 4 sets | **Accu SSC-M2-14-A2** cap screws, **HNN-M2-A2** nyloc nuts, **HPW-M2-A2** plain washers | Four sleeved pivots. CAD uses washer maximum **0.35 mm** and nut maximum **2.8 mm**; minimum one 0.4 mm thread pitch protrusion. Verify supplied dimensions. |
| 2 sets | **ISO 4762 A2 M2x16**, **ISO 10511 M2 nyloc nut**, M2 washers | Split keyed crank clamps; tighten with shaft installed and confirm no binding. |
| 2 / 2 sets | **ISO 4762 A2 M2x20 / M2x6**, matching **ISO 4032 M2** nuts | SDP810 housing / daughterboard mounts, plus two 0.4 mm washers on housing screws. |
| 4 sets | **ISO 4762 A2 M2x14**, **ISO 4032 M2** nuts and 0.4 mm washers | Two mounts per Adafruit 1782 temperature board. |
| 1 stock length / 4 cut pieces | **K&S Precision Metals 8128**, brass 260/272 tube, **5/32 inch OD × 0.014 inch wall × 12 inch stock length** | Fan compression-limiter stock: OD3.96875 mm, published ID3.2512 mm, OD/ID tolerance ±0.0508 mm. Cut four pieces to the measured mounting stack; independent study starts at28.70 mm for a trial15% TPU compression. Square/deburr and measure cuts. Corrected pad bore is4.4 mm; adoption into full assembly is pending. [Manufacturer specification](https://ksmetals.com/products/br014-5-32). |
| 1 custom cut | Clear acrylic window **45 x34.4 x1 mm** | Protects the 40.8 x30.6 mm active display; nominal 0.76 mm air gap, no diffuser. Material/source and dimensional coupon acceptance required before cutting the final window. |
| perimeter only | **3M 467MP**, 0.05 mm transfer adhesive | Bonds clear window to bezel; keep adhesive outside the visible area. |
| 2 sets | **ISO 4762 A2 M2x12**, **ISO 4032 A2 M2** nuts | Display's two actual PCB holes to removable cradle; support PCB, never compress the LCD glass. |
| 4 | **ISO 4762 A2 M2x6** | Removable display bezel into RX-M2x4 heat-set inserts, not tapped PETG. Verify screw engagement and insertion temperature on a coupon. |
| 4 | **ruthex RX-M2x4**, order **GE-M2x04-001** (70-piece pack) | Display-bezel inserts; 4 mm length, 3.6 mm maximum OD, 3.2 mm initial through pilot. Boss radius 3.2 mm gives 1.4 mm nominal plastic outside the insert, above the vendor 1.3 mm minimum; boss axial length 4.5 mm. [Manufacturer](https://www.ruthex.de/products/ruthex-gewindeeinsatz-m2-70-stuck-rx-m2x4-messing-gewindebuchsen). |
| 4 locations | **ISO 4762 A2 M3x8** + **ruthex RX-M3x5.7** inserts | Display cradle-to-shell allocation within provisional general M3/insert quantities; radius 4 mm bosses with Ø4 mm pilot give nominal 1.7 mm plastic outside the 4.6 mm insert, meeting the 1.6 mm minimum. Reconcile final product count before ordering. |
| 1 set | Included FEETECH 20T servo horn and retaining screw | Use real splined horn; bolt printed crank adapter to horn |
| as needed | **3M Scotch-Weld DP100 Plus Clear** epoxy | Magnet adhesive space plus mechanical cover; keep adhesive away from rotor/hinges |
| 1 spool | **Prusament PETG** (structural parts), dry before printing | 0.4 mm nozzle; avoid PLA near regulators and sustained clamp load |
| 1 spool | **BASF Ultrafuse TPU 95A** | Replaceable fan pads/bushings and desk feet; characterize compression/set |
| small amount | Natural translucent PETG | Ambient diffuser only; screen uses a clear protective window, never an opaque diffuser over the display |

The mechanical table is an initial purchasing allowance, not an exact released assembly fastener count. Hinge-linkage bearings, gears or return spring depend on the final verified CAD and kinematics. Do not substitute a guessed spring into the assembled system; it may overload or fail to backdrive the servo.

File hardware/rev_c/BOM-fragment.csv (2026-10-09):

Reference | Quantity | Manufacturer | Exact part or selected model | Function | Status
MOTOR1 | 1 | T-Motor / T-Hobby | Pacer V4 P2406 Juicy 2060KV | Single outrunner motor | Selected by user; exact shaft-seat and screw depth need measurement
ESC1 | 1 | TeamTriforceUK | A50S V2.3c 12S A50SV2.3c-12-10 | Single sensorless FOC ESC with UART telemetry | Selected candidate; low-speed compatibility unqualified
PD1 | 1 | Adafruit | 5807 HUSB238 | USB PD sink set to15V3A | Retain module; modify contract jumpers
PSU1 | 1 | Raspberry Pi | 45W USB-C Power Supply UK Type G white | 15V3A PD source | Retain selected supply
EF1-C | 1 | Texas Instruments | TPS26630RGER | Input eFuse 2.517A nominal with controlled inrush | New circuit and PCB required
EF2-C | 1 | Texas Instruments | TPS26630RGER | ESC branch eFuse 1.8A nominal default off | New circuit and PCB required
Q-RCB1 | 1 | Texas Instruments | CSD19537Q3 | Input reverse-current blocking FET | Use TI reference circuit; layout and sequencing required
Q-DRV1 | 1 | Diodes Incorporated | BSS138-7-F | Fast external blocking-FET gate pulldown | Use TI reference topology
U-GUARD-NOT / U-UART-NOT | 2 | Texas Instruments | SN74LVC1G04DBVR | Invert guard signal and ESC-PGOOD | New hardwired motor and UART gates
U-GUARD-AND | 1 | Texas Instruments | SN74LVC1G08DBVR | AND guard present with MCU power request | New hardwired motor gate
U-UART1 | 1 | Nexperia | 74LVC2G125DP-Q100H | Dual noninverting UART buffers with Ioff | Power from Pico3.3V and enable only when ESC branch PGOOD is HIGH
F1-C | 1 | Littelfuse | 0451003.MRL | 3A input branch fuse | Inrush and fault coordination require bench verification
F2-C | 1 | Littelfuse | 0451002.MRL | 2A ESC wiring fuse | Does not replace current or stall control
D-ESC | 1 | Littelfuse | SMBJ18A | ESC bus transient clamp | No continuous regenerative energy sink
C-ESC | 1 | Panasonic | EEU-FR1V471 | 470uF35V ESC-local bulk capacitor | Fit behind controlled-inrush switch plus local ceramic bypass
R-ESC-BLEED | 1 | Yageo | RC1206FR-073K3L | 3.3k0.25W ESC-capacitor bleed | Discharge remains finite; verify actual capacitor sum
R-EF1-ILIM | 1 | Yageo | RC0603FR-077K15L | 7.15k1% input-eFuse limit resistor | 2.517A nominal analytical
R-EF2-ILIM | 1 | Yageo | RC0603FR-0710KL | 10k1% ESC-eFuse limit resistor | 1.8A nominal analytical
R-EF2-SHDN | 1 | Yageo | RC0603FR-0710KL | 10k motor-branch shutdown pulldown | Default off during reset
J-ESC-POWER | 1 | Amass | XT30 male and female pair supplied with ESC | ESC power connection | Check actual supplied connector sex and keying
J-MOTOR | 1 | Amass | MR30 pair supplied with ESC | Three phase motor connection | Keep accessible and insulated
J-ESC-IO | 1 | Molex | 5011892010 board connector plus ESC-supplied shell and precrimped wires | UART and ground loom | Do not invent physical cavity numbers from unnumbered vendor figure

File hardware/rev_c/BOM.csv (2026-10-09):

Reference | Quantity | Manufacturer | Exact part/specification | Function | Location | Status
MOTOR1 | 1 | T-Motor | Pacer V4 P2406 Juicy2060KV | Single axial-impeller drive | assembly | Selected; physical qualification required
ESC1 | 1 | TeamTriforceUK | A50SV2.3c-12-10, A50S V2.3c12S | Single FOC ESC; UART speed/current/temperature | assembly | Selected; physical qualification required
PD1 | 1 | Adafruit | 5807 HUSB238 | 15V3A PD sink; exact15V contract required | assembly | Selected; physical qualification required
PSU1 | 1 | Raspberry Pi | 45W USB-C Power Supply UK TypeG white | 15V3A USB PD source, integral cable | assembly | Selected; physical qualification required
MCU1 | 1 | Raspberry Pi | Pico SC0915 | RP2040 controller; use Rev C firmware only | assembly | Selected; physical qualification required
SERVO1 | 1 | FEETECH / Pololu | FS90-FB / Pololu3436 | Feedback servo; supplied20T horn and retaining screw | assembly | Selected; physical qualification required
ENC1 | 1 | Bourns | PEC11H-4215F-S0024 | 24-detent horizontal push thumbwheel | assembly | Selected; physical qualification required
TFT1 | 1 | Adafruit | 4311,2-inch ST7789 IPS240x320 | Clear landscape display; top status band and wheel/countdown | assembly | Selected; physical qualification required
LED1 | 1 | Adafruit | 1426,8-pixel NeoPixel stick | Recessed downward ambient lighting | assembly | Selected; physical qualification required
TEMP1,TEMP2 | 2 | Adafruit | 1782 MCP9808 | Power-board-adjacent and base-air temperature; addresses0x18/0x19 | assembly | Selected; physical qualification required
DP1 | 1 | Sensirion | SDP810-125Pa,1-101597-01 | Restriction sensing; direct-solder2mm-pitch daughterboard required | assembly | Selected; physical qualification required
REG1,REG2 | 2 | Pololu | 2858 D24V22F5 | Separate5V logic and servo rails | assembly | Selected; physical qualification required
SW-GRILLE | 1 | Omron | D2F-01L | COM/NO magnetic-grille-present interlock | assembly | Selected; physical qualification required
MAG1..8 | 8 | K&J Magnetics | D42,N42 axial,6.35x3.175mm | Four captive opposing pairs; face gap1.925mm nominal | assembly | Selected; physical qualification required
HINGE1,2 | 2 | Metal stock supplier | Ground stainless steel rod3mm,cut172mm | Two panel hinge shafts, deburred | assembly | Selected; physical qualification required
COLLAR1..4 | 4 | Maedler | 62300300,DIN705A,3mm bore | Four shaft collars with suppliedM2x3 set screws | assembly | Selected; physical qualification required
HINGE-SPACER1,2 | 2 | Metal stock supplier | Stainless tube7mmOD/3.3mmID,cut7.6mm | Right-side shaft spacers | assembly | Selected; physical qualification required
PIVOT-SLEEVE1..4 | 4 | Metal stock supplier | Stainless tube3mmOD/2.1mmID;cuts9.1,9.1,9.6,8.6mm | Smooth sleeve bearings for4M2 pivot stacks | assembly | Selected; physical qualification required
PIVOT-SCREW1..4 | 4 | Accu | SSC-M2-14-A2 + HNN-M2-A2 + HPW-M2-A2 | Four metal-clamped linkage pivots | assembly | Selected; physical qualification required
CLAMP1,2 | 2 | ISO hardware supplier | ISO4762A2-70M2x16 / ISO10511M2 / ISO7089M2 | Keyed crank clamp sets | assembly | Selected; physical qualification required
LOOM-PICO-SOCKET | 2 | Wurth Elektronik | 61202023021,20pin IDC with strain relief | Mating J15/J16 sockets; new keyed loom, not E3 cable | assembly | Selected; physical qualification required
LOOM-PICO-WIRE | 2 | Cable supplier | 28AWG20way ribbon,1.27mm pitch,maximum150mm | Pico-side transition/strain relief still requires physical layout | assembly | Selected; physical qualification required
MOTOR-CONNECTOR | 1 | Amass | MR30 pair supplied with ESC | Three-phase loom; verify supplied connector sex | assembly | Selected; physical qualification required
ESC-POWER-CONNECTOR | 1 | Amass | XT30 pair supplied with ESC | Power loom from J20; verify supplied connector sex | assembly | Selected; physical qualification required
ESC-IO-LOOM | 1 | Molex / ESC supplier | 5011892010 interface,ESC-supplied mating shell and precrimped wires | Use vendor-labelled3.3V UART/GND; insulate BEC | assembly | Selected; physical qualification required
TUBE-DP | 1 | Saint-Gobain | TygonE-3603ACF00010,ID3.96875/OD7.14375mm | Cut matched hoses after Rev C route; minimum bend radius12.7mm | assembly | Selected; physical qualification required
WIRE-POWER | 1 | Alpha Wire | 3051,22AWG | Power branches; lengths from finished loom | assembly | Selected; physical qualification required
WIRE-SIGNAL | 1 | Alpha Wire | 5853,26AWG | Signal/feedback/I2C; twisted ground/UART where practical | assembly | Selected; physical qualification required
WINDOW | 1 | Acrylic supplier | Clear45x34.4x1mm cut sheet | Screen protective window; no diffuser over TFT | assembly | Selected; physical qualification required
WINDOW-ADHESIVE | 1 | 3M | 467MP,0.05mm | Window perimeter only | assembly | Selected; physical qualification required
MAGNET-ADHESIVE | 1 | 3M | Scotch-WeldDP100PlusClear | Allowed pocket glue, retained mechanically | assembly | Selected; physical qualification required
SERVICE-SHUNT | 1 | Samtec | SNT-100-BK-G | Calibration entry shunt for service header | assembly | Selected; physical qualification required
ESC-STRAP | 1 | Cable tie supplier | Nonconducting3mm-wide removable tie | ESC case restraint; qualify actual connector access | assembly | Selected; physical qualification required
J1 | 1 | See exact MPN | JST B2B-XH-A(LF)(SN) | XH 2; HUSB238 PD output; physical breakout is remote | carrier | Captured/checked circuit; board unrouted
F1 | 1 | See exact MPN | Littelfuse 0451003.MRL | 3A | carrier | Captured/checked circuit; board unrouted
D1 | 1 | See exact MPN | Littelfuse SMBJ18A | SMBJ18A | carrier | Captured/checked circuit; board unrouted
C1 | 1 | See exact MPN | Murata GRM188R71H104KA93D | 100nF | carrier | Captured/checked circuit; board unrouted
C2 | 1 | See exact MPN | Panasonic EEU-FR1E101 | 100uF/25V | carrier | Captured/checked circuit; board unrouted
J18 | 1 | See exact MPN | Molex 43045-0412 | 43045-0412; Remote regulator; different shrouded cavity count. Module EN is NC. Mating/placement qualification pending | carrier | Captured/checked circuit; board unrouted
J19 | 1 | See exact MPN | Molex 43045-0812 | 43045-0812; Remote regulator; different shrouded cavity count. Module EN is NC. Mating/placement qualification pending | carrier | Captured/checked circuit; board unrouted
C4 | 1 | See exact MPN | Murata GRM188R71E105KA12D | 1uF | carrier | Captured/checked circuit; board unrouted
C7 | 1 | See exact MPN | Panasonic EEU-FR1E101 | 100uF/25V | carrier | Captured/checked circuit; board unrouted
C5 | 1 | See exact MPN | Murata GRM188R71E105KA12D | 1uF | carrier | Captured/checked circuit; board unrouted
C8 | 1 | See exact MPN | Panasonic EEU-FR1E101 | 100uF/25V | carrier | Captured/checked circuit; board unrouted
D2 | 1 | See exact MPN | Vishay SS14-E3/61T | SS14-E3/61T | carrier | Captured/checked circuit; board unrouted
F3 | 1 | See exact MPN | Littelfuse 0451001.MRL | 1A | carrier | Captured/checked circuit; board unrouted
SW2 | 1 | See exact MPN | Texas Instruments TPS22810DBVR | TPS22810DBVR | carrier | Captured/checked circuit; board unrouted
C12 | 1 | See exact MPN | Murata GRM188R71E105KA12D | 1uF | carrier | Captured/checked circuit; board unrouted
C15 | 1 | See exact MPN | Murata GRM188R71H104KA93D | 100nF | carrier | Captured/checked circuit; board unrouted
R40 | 1 | See exact MPN | Yageo RC1206FR-07330RL | 330 1% | carrier | Captured/checked circuit; board unrouted
R11 | 1 | See exact MPN | Yageo RC0603FR-07100KL | 100k 1% | carrier | Captured/checked circuit; board unrouted
BUF3 | 1 | See exact MPN | Nexperia 74AHCT1G125GW,125 | 74AHCT1G125GW,125 | carrier | Captured/checked circuit; board unrouted
C19 | 1 | See exact MPN | Murata GRM188R71H104KA93D | 100nF | carrier | Captured/checked circuit; board unrouted
R23 | 1 | See exact MPN | Yageo RC0603FR-07100KL | 100k 1% | carrier | Captured/checked circuit; board unrouted
R17 | 1 | See exact MPN | Yageo RC0603FR-07330RL | 330 1% | carrier | Captured/checked circuit; board unrouted
R24 | 1 | See exact MPN | Yageo RC0603FR-07100KL | 100k 1% | carrier | Captured/checked circuit; board unrouted
C9 | 1 | See exact MPN | Panasonic EEU-FR1A471 | 470uF/10V | carrier | Captured/checked circuit; board unrouted
J4 | 1 | See exact MPN | Samtec TSW-103-07-G-S | 2.54mm 3; Original servo plug, retain and label polarity | carrier | Captured/checked circuit; board unrouted
J5 | 1 | See exact MPN | Samtec TSW-101-07-G-S | 2.54mm 1 | carrier | Captured/checked circuit; board unrouted
R8 | 1 | See exact MPN | Yageo RC0603FR-074K7L | 4.7k 1% | carrier | Captured/checked circuit; board unrouted
SW3 | 1 | See exact MPN | Texas Instruments TPS22810DBVR | TPS22810DBVR | carrier | Captured/checked circuit; board unrouted
C13 | 1 | See exact MPN | Murata GRM188R71E105KA12D | 1uF | carrier | Captured/checked circuit; board unrouted
C16 | 1 | See exact MPN | Murata GRM188R71H104KA93D | 100nF | carrier | Captured/checked circuit; board unrouted
R41 | 1 | See exact MPN | Yageo RC1206FR-07330RL | 330 1% | carrier | Captured/checked circuit; board unrouted
R12 | 1 | See exact MPN | Yageo RC0603FR-07100KL | 100k 1% | carrier | Captured/checked circuit; board unrouted
C10 | 1 | See exact MPN | Panasonic EEU-FR1A471 | 470uF/10V | carrier | Captured/checked circuit; board unrouted
BUF1 | 1 | See exact MPN | Nexperia 74AHCT125D,118 | 74AHCT125D,118 | carrier | Captured/checked circuit; board unrouted
C17 | 1 | See exact MPN | Murata GRM188R71H104KA93D | 100nF | carrier | Captured/checked circuit; board unrouted
R19 | 1 | See exact MPN | Yageo RC0603FR-07100KL | 100k 1% | carrier | Captured/checked circuit; board unrouted
R16 | 1 | See exact MPN | Yageo RC0603FR-07330RL | 330 1% | carrier | Captured/checked circuit; board unrouted
J7 | 1 | See exact MPN | JST B3B-XH-A(LF)(SN) | XH 3 | carrier | Captured/checked circuit; board unrouted
J2 | 1 | See exact MPN | JST B3B-XH-A(LF)(SN) | XH 3; HUSB238 I2C only; PD voltage must not enter sensor headers | carrier | Captured/checked circuit; board unrouted
J8 | 1 | See exact MPN | JST B4B-XH-A(LF)(SN) | XH 4; Exact encoder daughterboard J1 pin order | carrier | Captured/checked circuit; board unrouted
J9 | 1 | See exact MPN | JST B4B-XH-A(LF)(SN) | XH 4 | carrier | Captured/checked circuit; board unrouted
J10 | 1 | See exact MPN | JST B4B-XH-A(LF)(SN) | XH 4 | carrier | Captured/checked circuit; board unrouted
J11 | 1 | See exact MPN | JST B4B-XH-A(LF)(SN) | XH 4 | carrier | Captured/checked circuit; board unrouted
R1 | 1 | See exact MPN | Yageo RC0603FR-0710KL | 10k 1% | carrier | Captured/checked circuit; board unrouted
C26 | 1 | See exact MPN | Murata GRM188R71C103KA01D | 10nF | carrier | Captured/checked circuit; board unrouted
R2 | 1 | See exact MPN | Yageo RC0603FR-0710KL | 10k 1% | carrier | Captured/checked circuit; board unrouted
C27 | 1 | See exact MPN | Murata GRM188R71C103KA01D | 10nF | carrier | Captured/checked circuit; board unrouted
R3 | 1 | See exact MPN | Yageo RC0603FR-0710KL | 10k 1% | carrier | Captured/checked circuit; board unrouted
C28 | 1 | See exact MPN | Murata GRM188R71C103KA01D | 10nF | carrier | Captured/checked circuit; board unrouted
R6 | 0 | See exact MPN | Yageo RC0603FR-074K7L | 4.7k 1% | carrier | DNP
R7 | 0 | See exact MPN | Yageo RC0603FR-074K7L | 4.7k 1% | carrier | DNP
C22 | 1 | See exact MPN | Murata GRM188R71H104KA93D | 100nF | carrier | Captured/checked circuit; board unrouted
C33 | 1 | See exact MPN | Murata GRM188R71H104KA93D | 100nF | pressure_daughterboard | Captured/checked circuit; board unrouted
J12 | 1 | See exact MPN | JST B2B-XH-A(LF)(SN) | XH 2; Omron COM/NO; raw5V input goes to BUF4, never to GPIO | carrier | Captured/checked circuit; board unrouted
R5 | 1 | See exact MPN | Yageo RC0603FR-073K9L | 3.9k 1% | carrier | Captured/checked circuit; board unrouted
BUF4 | 1 | See exact MPN | Texas Instruments SN74LVC1G17DBVR | SN74LVC1G17DBVR | carrier | Captured/checked circuit; board unrouted
C31 | 1 | See exact MPN | Murata GRM188R71H104KA93D | 100nF | carrier | Captured/checked circuit; board unrouted
C32 | 1 | See exact MPN | Murata GRM188R71C103KA01D | 10nF | carrier | Captured/checked circuit; board unrouted
R60 | 1 | See exact MPN | Yageo RC0603FR-07100KL | 100k 1% | carrier | Captured/checked circuit; board unrouted
J14 | 1 | See exact MPN | Samtec TSW-102-07-G-S | 2.54mm 2; Removable SNT-100-BK-G service shunt | carrier | Captured/checked circuit; board unrouted
J15 | 1 | See exact MPN | Wurth Elektronik 61202021621 | Keyed IDC20; All20 contacts retained. New keyed2x10 loom with61202023021 sockets; no E3 contact-removal key. | carrier | Captured/checked circuit; board unrouted
J16 | 1 | See exact MPN | Wurth Elektronik 61202021621 | Keyed IDC20; All20 contacts retained. New keyed2x10 loom with61202023021 sockets; no E3 contact-removal key. | carrier | Captured/checked circuit; board unrouted
ISO1 | 1 | See exact MPN | Texas Instruments TMUX1511PWR | TMUX1511PWR | carrier | Captured/checked circuit; board unrouted
SUP1 | 1 | See exact MPN | Texas Instruments TPS3808G33DBVR | TPS3808G33DBVR | carrier | Captured/checked circuit; board unrouted
C20 | 1 | See exact MPN | Murata GRM188R71H104KA93D | 100nF | carrier | Captured/checked circuit; board unrouted
C21 | 1 | See exact MPN | Murata GRM188R71H104KA93D | 100nF | carrier | Captured/checked circuit; board unrouted
R37 | 1 | See exact MPN | Yageo RC0603FR-0710KL | 10k 1% | carrier | Captured/checked circuit; board unrouted
R38 | 1 | See exact MPN | Yageo RC0603FR-07100KL | 100k 1% | carrier | Captured/checked circuit; board unrouted
R28 | 1 | See exact MPN | Yageo RC0603FR-07100KL | 100k 1% | carrier | Captured/checked circuit; board unrouted
R29 | 1 | See exact MPN | Yageo RC0603FR-0710KL | 10k 1% | carrier | Captured/checked circuit; board unrouted
R30 | 1 | See exact MPN | Yageo RC0603FR-071ML | 1M 1% | carrier | Captured/checked circuit; board unrouted
C23 | 1 | See exact MPN | Murata GRM188R71H104KA93D | 100nF | carrier | Captured/checked circuit; board unrouted
R31 | 1 | See exact MPN | Yageo RC0603FR-07100KL | 100k 1% | carrier | Captured/checked circuit; board unrouted
R32 | 1 | See exact MPN | Yageo RC0603FR-07100KL | 100k 1% | carrier | Captured/checked circuit; board unrouted
R33 | 1 | See exact MPN | Yageo RC0603FR-071ML | 1M 1% | carrier | Captured/checked circuit; board unrouted
C24 | 1 | See exact MPN | Murata GRM188R71H104KA93D | 100nF | carrier | Captured/checked circuit; board unrouted
R34 | 1 | See exact MPN | Yageo RC0603FR-07100KL | 100k 1% | carrier | Captured/checked circuit; board unrouted
R35 | 1 | See exact MPN | Yageo RC0603FR-07100KL | 100k 1% | carrier | Captured/checked circuit; board unrouted
R36 | 1 | See exact MPN | Yageo RC0603FR-071ML | 1M 1% | carrier | Captured/checked circuit; board unrouted
C25 | 1 | See exact MPN | Murata GRM188R71H104KA93D | 100nF | carrier | Captured/checked circuit; board unrouted
BUF2 | 1 | See exact MPN | Nexperia 74AHCT125D,118 | 74AHCT125D,118 | carrier | Captured/checked circuit; board unrouted
C18 | 1 | See exact MPN | Murata GRM188R71H104KA93D | 100nF | carrier | Captured/checked circuit; board unrouted
R50 | 1 | See exact MPN | Yageo RC0603FR-0733RL | 33 1% | carrier | Captured/checked circuit; board unrouted
R51 | 1 | See exact MPN | Yageo RC0603FR-0733RL | 33 1% | carrier | Captured/checked circuit; board unrouted
R52 | 1 | See exact MPN | Yageo RC0603FR-0733RL | 33 1% | carrier | Captured/checked circuit; board unrouted
R53 | 1 | See exact MPN | Yageo RC0603FR-0733RL | 33 1% | carrier | Captured/checked circuit; board unrouted
R54 | 1 | See exact MPN | Yageo RC0603FR-0733RL | 33 1% | carrier | Captured/checked circuit; board unrouted
R55 | 1 | See exact MPN | Yageo RC0603FR-07330RL | 330 1% | carrier | Captured/checked circuit; board unrouted
R56 | 1 | See exact MPN | Yageo RC0603FR-071KL | 1k 1% | display_harness | Captured/checked circuit; board unrouted
R57 | 1 | See exact MPN | Yageo RC0603FR-0710KL | 10k 1% | carrier | Captured/checked circuit; board unrouted
R58 | 1 | See exact MPN | Yageo RC0603FR-0710KL | 10k 1% | carrier | Captured/checked circuit; board unrouted
R59 | 1 | See exact MPN | Yageo RC0603FR-07100KL | 100k 1% | carrier | Captured/checked circuit; board unrouted
C30 | 1 | See exact MPN | Murata GRM188R71E105KA12D | 1uF | display_harness | Captured/checked circuit; board unrouted
J6 | 1 | See exact MPN | JST B8B-XH-A(LF)(SN) | XH 8 | carrier | Captured/checked circuit; board unrouted
EF1 | 1 | See exact MPN | Texas Instruments TPS26630RGER | TPS26630RGER | carrier | Captured/checked circuit; board unrouted
EF2 | 1 | See exact MPN | Texas Instruments TPS26630RGER | TPS26630RGER | carrier | Captured/checked circuit; board unrouted
R61 | 1 | See exact MPN | Yageo RC0603FR-077K15L | 7.15k 1% | carrier | Captured/checked circuit; board unrouted
R62 | 1 | See exact MPN | Yageo RC0603FR-07100KL | 100k 1% | carrier | Captured/checked circuit; board unrouted
R63 | 1 | See exact MPN | Yageo RC0603FR-0710KL | 10k 1% | carrier | Captured/checked circuit; board unrouted
R64 | 1 | See exact MPN | Yageo RC0603FR-07132KL | 132k 1% | carrier | Captured/checked circuit; board unrouted
R65 | 1 | See exact MPN | Yageo RC0603FR-0710KL | 10k 1% | carrier | Captured/checked circuit; board unrouted
R71 | 1 | See exact MPN | Yageo RC0603FR-07100KL | 100k 1% | carrier | Captured/checked circuit; board unrouted
R72 | 1 | See exact MPN | Yageo RC0603FR-0710KL | 10k 1% | carrier | Captured/checked circuit; board unrouted
C34 | 1 | See exact MPN | Murata GRM188R71H104KA93D | 100nF | carrier | Captured/checked circuit; board unrouted
C36 | 1 | See exact MPN | Murata GRM188R71E105KA12D | 1uF | carrier | Captured/checked circuit; board unrouted
R66 | 1 | See exact MPN | Yageo RC0603FR-0710KL | 10k 1% | carrier | Captured/checked circuit; board unrouted
R67 | 1 | See exact MPN | Yageo RC0603FR-07100KL | 100k 1% | carrier | Captured/checked circuit; board unrouted
R68 | 1 | See exact MPN | Yageo RC0603FR-0710KL | 10k 1% | carrier | Captured/checked circuit; board unrouted
R69 | 1 | See exact MPN | Yageo RC0603FR-07132KL | 132k 1% | carrier | Captured/checked circuit; board unrouted
R70 | 1 | See exact MPN | Yageo RC0603FR-0710KL | 10k 1% | carrier | Captured/checked circuit; board unrouted
R76 | 1 | See exact MPN | Yageo RC0603FR-07100KL | 100k 1% | carrier | Captured/checked circuit; board unrouted
R77 | 1 | See exact MPN | Yageo RC0603FR-0710KL | 10k 1% | carrier | Captured/checked circuit; board unrouted
C35 | 1 | See exact MPN | Murata GRM188R71H104KA93D | 100nF | carrier | Captured/checked circuit; board unrouted
C37 | 1 | See exact MPN | Murata GRM188R71E105KA12D | 1uF | carrier | Captured/checked circuit; board unrouted
QRC1 | 1 | See exact MPN | Texas Instruments CSD19537Q3 | CSD19537Q3; Actual drawing: source1..3, gate4, drain5..8+EP. Shared drain land represented by common pad5. | carrier | Captured/checked circuit; board unrouted
QDRV1 | 1 | See exact MPN | Diodes Incorporated BSS138-7-F | BSS138-7-F | carrier | Captured/checked circuit; board unrouted
F2 | 1 | See exact MPN | Littelfuse 0451002.MRL | 2A | carrier | Captured/checked circuit; board unrouted
J20 | 1 | See exact MPN | Molex 43045-0212 | ESC power; Adapter loom to suppliedXT30; no3A motor power through Pico/ribbon. | carrier | Captured/checked circuit; board unrouted
J22 | 1 | See exact MPN | JST B3B-XH-A(LF)(SN) | XH 3; Adapter to vendor-labelled GND/RX/TX wires. Verify A50S20-cavity loom; BEC insulated NC. | carrier | Captured/checked circuit; board unrouted
C38 | 1 | See exact MPN | Panasonic EEU-FR1V471 | 470uF/35V | esc_harness | Captured/checked circuit; board unrouted
C39 | 1 | See exact MPN | Murata GRM188R71E105KA12D | 1uF | esc_harness | Captured/checked circuit; board unrouted
D3 | 1 | See exact MPN | Littelfuse SMBJ18A | SMBJ18A | esc_harness | Captured/checked circuit; board unrouted
R80 | 1 | See exact MPN | Yageo RC1206FR-073K3L | 3.3k 1% | esc_harness | Captured/checked circuit; board unrouted
R81 | 1 | See exact MPN | Yageo RC0603FR-0710KL | 10k 1% | carrier | Captured/checked circuit; board unrouted
R82 | 1 | See exact MPN | Yageo RC0603FR-0710KL | 10k 1% | carrier | Captured/checked circuit; board unrouted
R83 | 1 | See exact MPN | Yageo RC0603FR-0710KL | 10k 1% | carrier | Captured/checked circuit; board unrouted
U1 | 1 | See exact MPN | Texas Instruments SN74LVC1G04DBVR | SN74LVC1G04DBVR | carrier | Captured/checked circuit; board unrouted
U2 | 1 | See exact MPN | Texas Instruments SN74LVC1G04DBVR | SN74LVC1G04DBVR | carrier | Captured/checked circuit; board unrouted
U3 | 1 | See exact MPN | Texas Instruments SN74LVC1G08DBVR | SN74LVC1G08DBVR | carrier | Captured/checked circuit; board unrouted
BUF5 | 1 | See exact MPN | Nexperia 74LVC2G125DP-Q100H | 74LVC2G125DP-Q100H | carrier | Captured/checked circuit; board unrouted
R84 | 1 | See exact MPN | Yageo RC0603FR-0710KL | 10k 1% | carrier | Captured/checked circuit; board unrouted
R85 | 1 | See exact MPN | Yageo RC0603FR-0710KL | 10k 1% | carrier | Captured/checked circuit; board unrouted
R86 | 1 | See exact MPN | Yageo RC0603FR-0733RL | 33 1% | carrier | Captured/checked circuit; board unrouted
R87 | 1 | See exact MPN | Yageo RC0603FR-0733RL | 33 1% | carrier | Captured/checked circuit; board unrouted
C40 | 1 | See exact MPN | Murata GRM188R71H104KA93D | 100nF | carrier | Captured/checked circuit; board unrouted
C41 | 1 | See exact MPN | Murata GRM188R71H104KA93D | 100nF | carrier | Captured/checked circuit; board unrouted
C42 | 1 | See exact MPN | Murata GRM188R71H104KA93D | 100nF | carrier | Captured/checked circuit; board unrouted
C43 | 1 | See exact MPN | Murata GRM188R71H104KA93D | 100nF | carrier | Captured/checked circuit; board unrouted
J21 | 0 | See exact MPN | JST B3B-XH-A(LF)(SN) | XH 3; DNP optical RPM service header; no unqualified sensor trusted | carrier | DNP
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

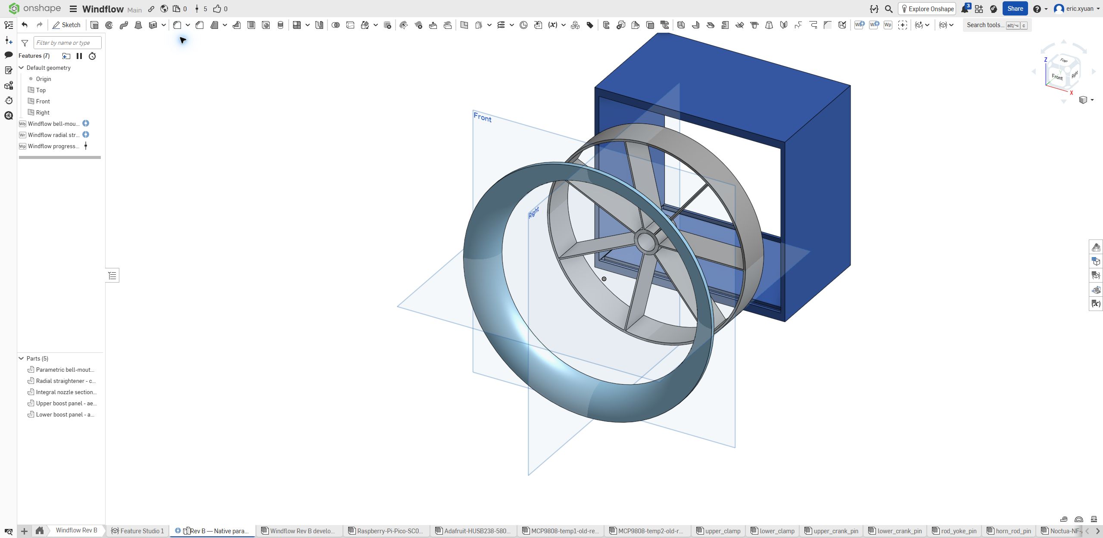
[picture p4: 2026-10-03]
cad/evidence/onshape-native-airflow-five-parts-2026-10-03.jpg

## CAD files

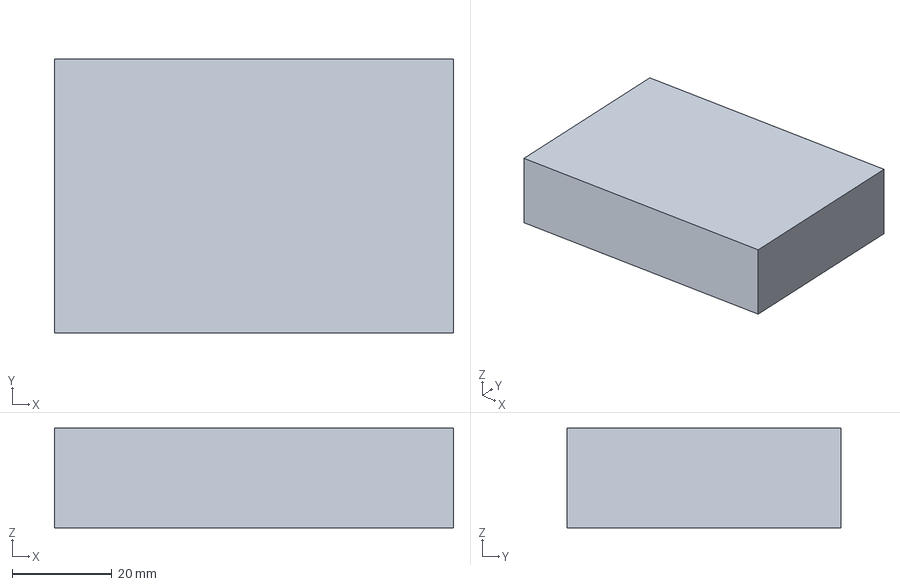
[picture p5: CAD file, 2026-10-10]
cad/rev_d/REF-main-PCB-population-and-loom-reserve-NOT-INTEGRATED.step
80.0 x 55.0 x 20.0 mm

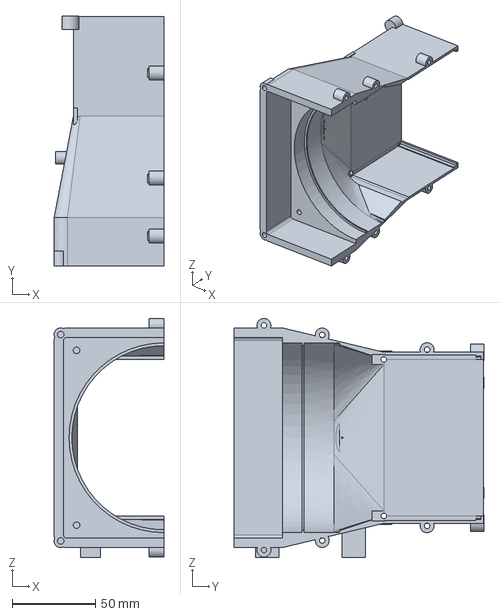
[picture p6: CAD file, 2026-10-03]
cad/fan_mount_study/baseline/head-left-integral-outlet.step
66.0 x 150.2 x 143.7 mm

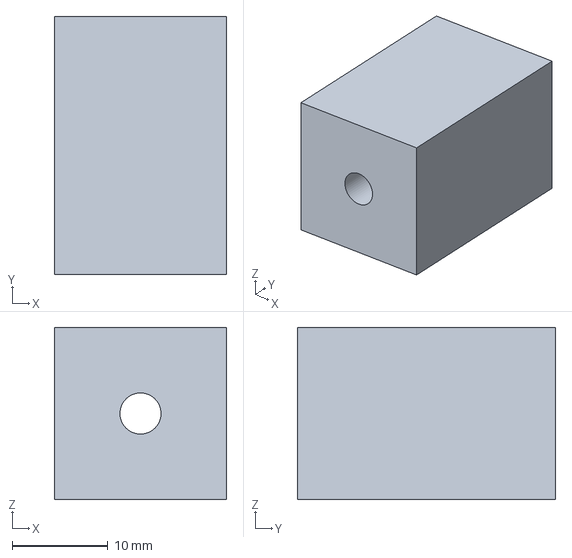
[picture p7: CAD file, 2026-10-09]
cad/fan_mount_study/fan-corner-27mm-stack-coupon.step
18.0 x 27.0 x 18.0 mm

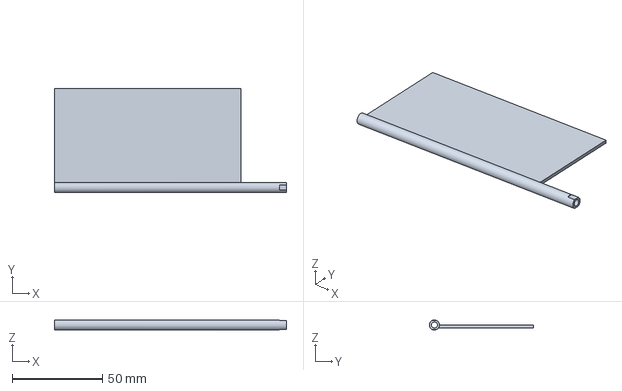
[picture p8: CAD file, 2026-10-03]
cad/grille_interlock_study/baseline/prototypes/installed-lower_panel-open.step
128.7 x 57.8 x 5.60 mm

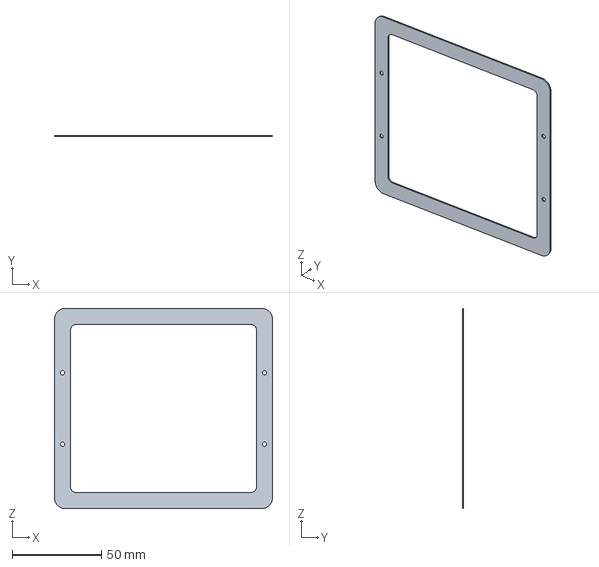
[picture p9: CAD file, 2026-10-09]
cad/grille_interlock_study/baseline/rev_b/grille-magnet-retaining-rim.step
122.0 x 0.8 x 112.0 mm

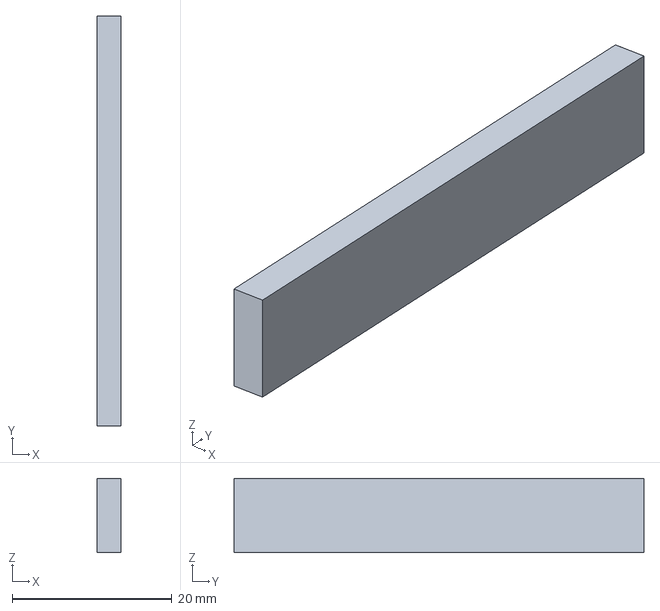
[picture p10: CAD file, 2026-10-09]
cad/interface_study/REF-carrier-J16-IDSS-socket.step
3.00 x 51.3 x 9.27 mm

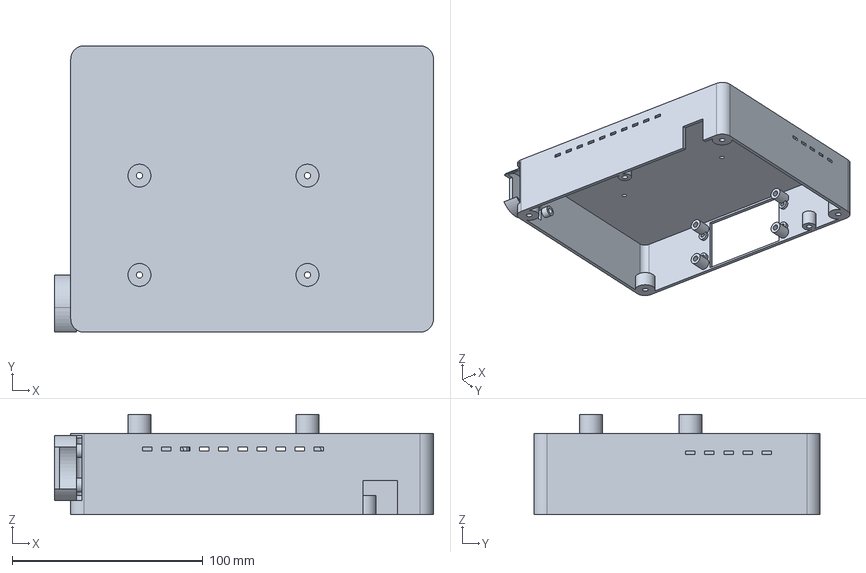
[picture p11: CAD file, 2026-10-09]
cad/pressure_plumbing_study/baseline/electronics-base-shell.step
198.5 x 150.0 x 52.4 mm

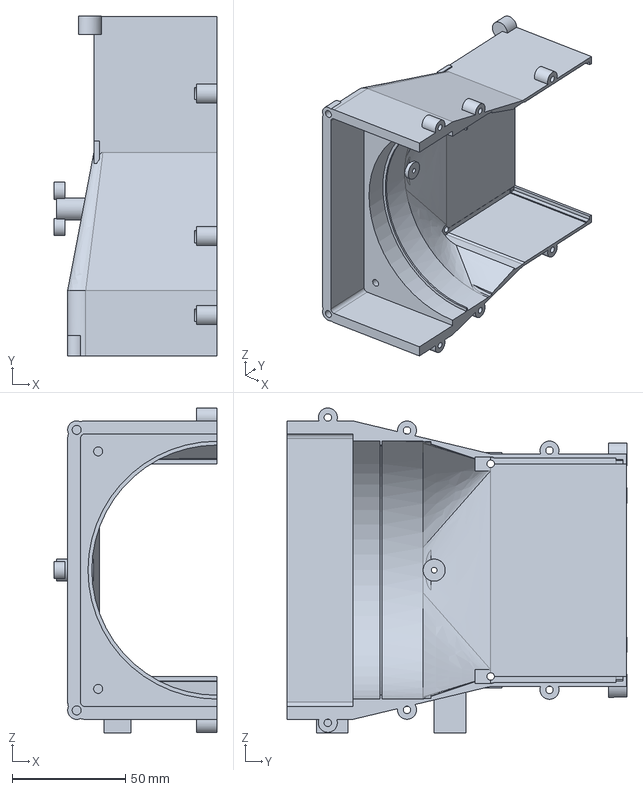
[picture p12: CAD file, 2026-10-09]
cad/pressure_plumbing_study/STUDY-head-left-pressure-receiver.step
72.0 x 150.2 x 143.7 mm

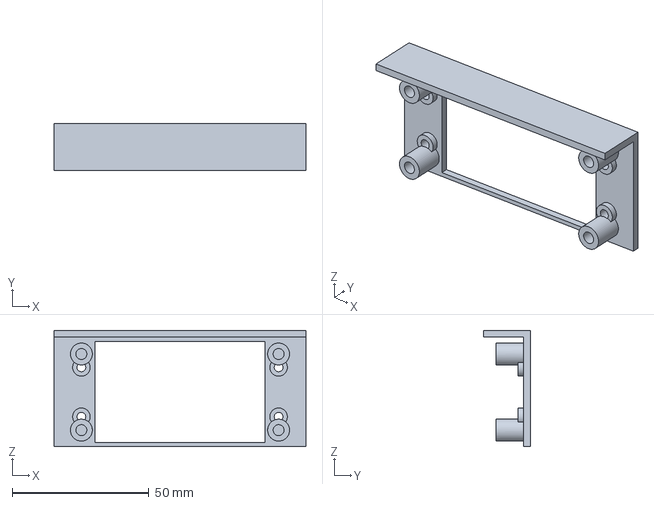
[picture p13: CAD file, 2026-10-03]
cad/prototypes/display-fascia-coupon.step
92.0 x 17.0 x 42.4 mm

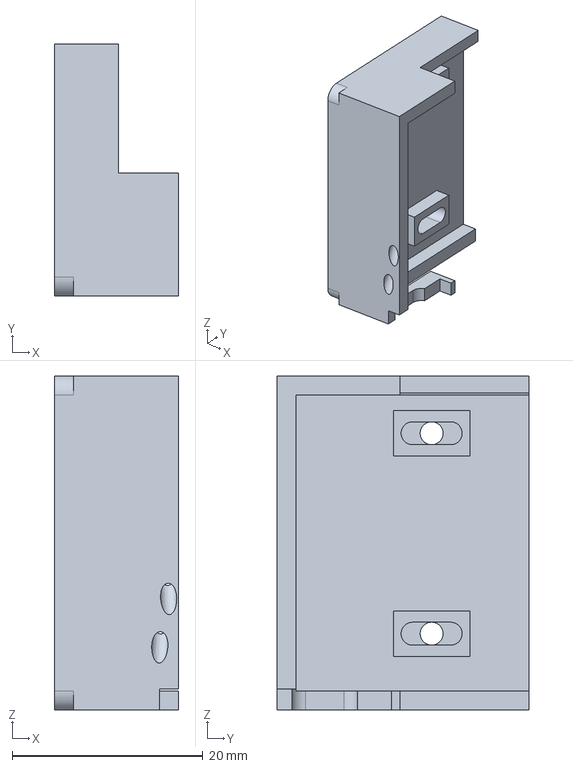
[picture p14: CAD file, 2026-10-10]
cad/rev_d/interlock-study/interlock-protective-cover-development.step
13.0 x 26.4 x 35.0 mm

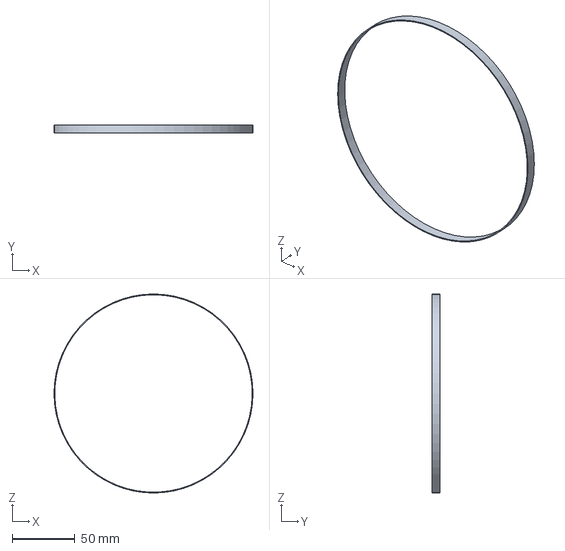
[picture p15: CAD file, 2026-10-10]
cad/rev_d/P2-TPU-carrier-isolation-ring.step
158.1 x 6.70 x 158.1 mm

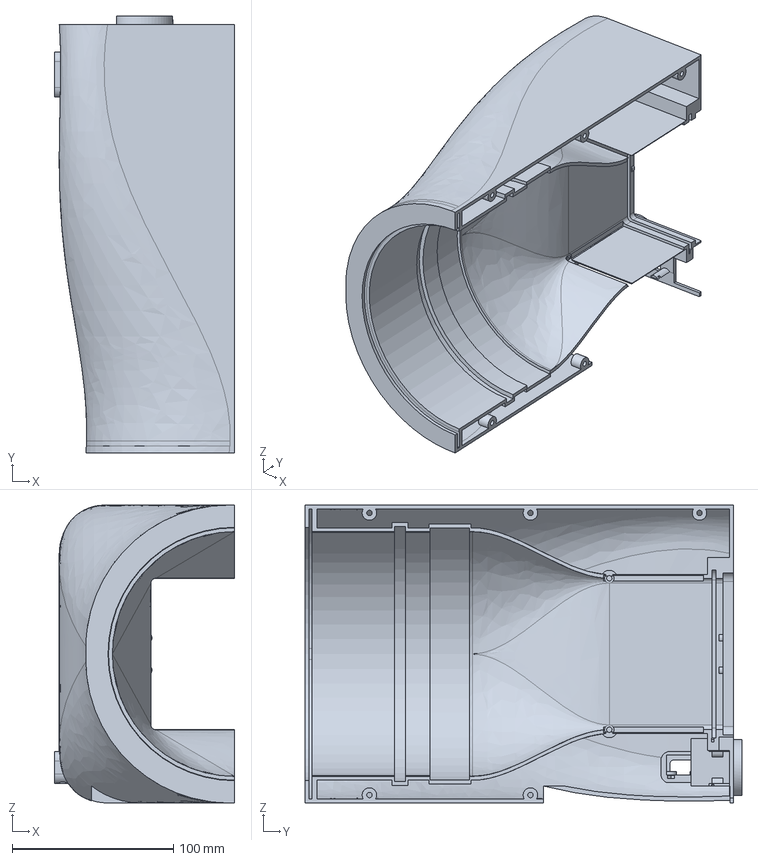
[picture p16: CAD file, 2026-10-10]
cad/rev_d/power-access-study/USB-side-port-head-left-CANDIDATE.step
112.1 x 271.4 x 185.0 mm

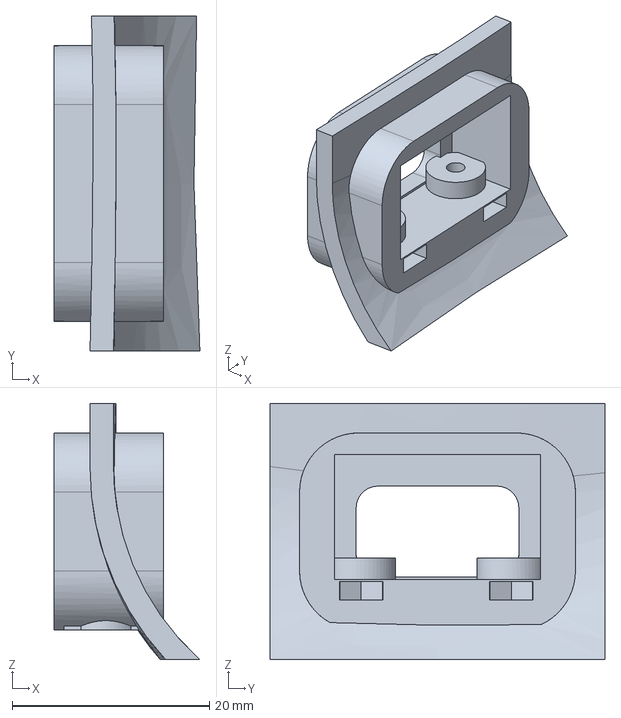
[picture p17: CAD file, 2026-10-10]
cad/rev_d/testpieces/USB-side-port-fit-coupon.step
14.8 x 34.0 x 26.0 mm

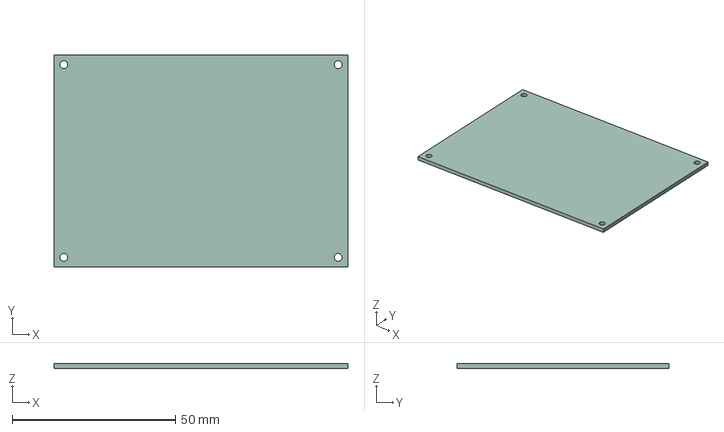
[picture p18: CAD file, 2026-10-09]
hardware/pcb/carrier-mechanical/carrier-mechanical-kicad.step
90.0 x 65.0 x 1.51 mm

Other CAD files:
rotor_selection/cad/rev_c/impeller-P1-GUARDED-TEST-ONLY.step
cad/fan_mount_study/baseline/tpu-fan-pad-m3.step
cad/fan_mount_study/tpu-fan-pad-bore-coupon-4p6.step
cad/fan_mount_study/REF-ISO4762-M3x35-1.step
cad/fan_mount_study/REF-ISO4762-M3x35-2.step
cad/fan_mount_study/REF-ISO4762-M3x35-3.step
cad/fan_mount_study/REF-ISO4762-M3x35-4.step
cad/fan_mount_study/REF-ISO7089-M3-washer-1.step
cad/fan_mount_study/REF-ISO7089-M3-washer-2.step
cad/fan_mount_study/REF-ISO7089-M3-washer-3.step
cad/fan_mount_study/REF-ISO7089-M3-washer-4.step
cad/fan_mount_study/REF-KS8128-brass-tube-1.step
cad/fan_mount_study/REF-KS8128-brass-tube-2.step
cad/fan_mount_study/REF-KS8128-brass-tube-3.step
cad/fan_mount_study/REF-KS8128-brass-tube-4.step
cad/fan_mount_study/REF-KS8128-brass-tube-cut-28p7.step
cad/fan_mount_study/REF-RX-M3x5p7-smooth-insert-1.step
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

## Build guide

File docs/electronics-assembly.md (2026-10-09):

# Electronics assembly and commissioning

Use the E3 [BOM](../hardware/BOM.md), [wiring specification](../hardware/wiring.md), [power budget](../hardware/power-budget.md) and [circuit review](../hardware/circuit-review.md) together. The firmware uses schema3 calibration, a 320 × 240 IPS screen and the revised divider scales. Recommission an older settings record; do not copy schema2 data into schema3. This document specifies how to build the electronics; it does not claim that the required carrier PCB already exists.

## Build prerequisites

The main carrier mechanical board is 90 × 65 × 1.6 mm, with a 22 mm overall populated-height reserve. Four Ø2.4 mm NPTH mounting holes are fixed at board coordinates (3,3), (3,62), (87,3), (87,62), matching the current tray. The mechanical KiCad blank exists in `hardware/pcb/carrier-mechanical`; the captured carrier schematic now exists separately and still needs final placement/routing release. Pico, PD board and the three regulator modules are separately mounted. Resolve their physical harness connections rather than assuming a carrier socket directly holds each remote board. The [carrier interface study](../hardware/carrier-interface-study.md) records a keyed Pico candidate and its limits. Encoder P1 is already routed and checked; the SDP810 pressure board is a separate direct-solder design in progress. Leave room for plugs, removal tools and wiring bends outside the bare board outline.

Create schematic symbols and footprints from the exact manufacturer package drawings listed in the circuit review, then run ERC/DRC and a schematic-to-BOM reference check. EF1 has a thermal pad: use stencil/reflow assembly and inspect the pad/thermal-via process. A general-purpose SOIC adapter or solderless breadboard does not provide the documented thermal design. Have the carrier fabricated and SMD-populated by a PCB assembly service if suitable reflow equipment and inspection are unavailable. No Gerbers or assembly service order are implied by this project state.

For the Bourns encoder, follow its solder-process limitations on the daughterboard; its data sheet discourages hand soldering. Provide mechanical bushing support so pressing the horizontal-axis wheel does not bend the PCB pins. Hold connectors and modules with screws or printed clamps so solder joints do not carry insertion or cable strain.

## Assembly order

1. Populate the carrier's SMD parts, fuses and connectors. Inspect all polarities and pin1 marks, especially the different SOT23-6 pinouts, SS14, TVS and electrolytics. Leave Pico and all loads disconnected. Confirm no low-resistance short across raw input, protected input,12 V,5 V or3.3 V.
2. Configure HUSB238: cut the default5 V and1 A links; close15 V and2 A. Check cut links are open electrically. Use its native USB-C connector and mechanically support the PCB. Do not modify or open the external mains adapter.
3. Secure REG1/2/3 independently on the tray. Complete the reviewed remote harness/socket design before connecting their carrier interfaces; the current mechanical separation does not permit direct insertion into the former carrier-mounted socket concept. Verify VIN/GND/VOUT/PG from each module's silkscreen. EN pads remain disconnected; REG1/3 PG route only to their pullups and Pico inputs. Route each high-current return directly to the carrier/regulator ground path.
4. Test EF1 and the three unloaded regulator rails using a protected bench source. Confirm about12 V,5 V and5 V; confirm OVP turns the protected bus off before it can become an unsupported high input. Verify the intended current limit with an electronic load. Remove power and let capacitors discharge before changing connections.
5. Program the detached Pico using a USB-C-to-micro-B data cable and the built UF2. Mount the Pico on its tray datums and use the completed, reviewed carrier harness; connect only the sensors, encoder and screen, then power through the specified PD supply. Confirm 3.3 V, screen status and sensor diagnostics. Connect the screen VIN to the unswitched REG2 logic 5 V rail. BUF2 buffers CS and RST because their onboard 10 kΩ pullups connect to VIN; never connect these pulled-up pins directly to Pico GPIO. Its third channel buffers GP16 backlight PWM: A9=GP16 with R59=100k pulldown, OE10=GND, Y8 through R55=330 Ω to BL. Fit R56=1k from BL to GND at the screen. Check powered reset/LOW, driven HIGH and disconnected-harness behavior before enabling PWM. Verify visible darkness during reset/night zero and all rail transitions; nominal calculations alone do not establish optical off. If using USB alone with PD disconnected, disconnect J2 until the PD board's unpowered I2C behavior has been checked.
6. Connect one load at a time: fan with fixed guard, downward ambient stick, then servo with horn disconnected. Confirm the switched supplies are off during boot/uncommissioned state; the screen remains available on logic power for fault/service indication. Test each output in service mode before attaching the linkage. Use the actual calibrated open pulse before installing the horn; do not assume1500 us is the correct mechanical open position.
7. Attach and secure the servo feedback plug, eight-position J6 screen loom, ambient power/data, guard switch and temperature boards. Verify the J6 pin order against wiring.md at both ends. Label identical XH housings; a keyed connector prevents reversal but does not prevent plugging an unrelated same-size connector into the wrong socket. Use local loom labels and distinct physical routing.
8. Place TEMP1 near the regulator hot region with a repeatable thermally coupled mount, clear of bare power contacts; TEMP2 senses the fan/base air. Route equal short pressure tubes to the static taps; identify the positive and reference ports, protect against pinching and keep them out of rotor/linkage motion.
9. Enter service with the recessed jumper and deliberate boot hold, then follow [calibration](calibration.md). Record PWM/RPM, all five position points, pressure zero and voltage calibration before committing. Remove the jumper after commissioning. Test shutdown, night mode, startup, guard opening, sensor disconnection and saved-setting recovery.

## Enclosure installation

Complete the electrical checks outside the enclosure first. Install the boards so every connector is reachable from the service opening. Use insulating standoffs and leave clearance under PCB solder joints; keep metal washers and inserts clear of traces. Keep the top status section of the screen visible. Secure the servo, screen and ambient looms with relaxed service loops, then exercise the whole nozzle range while observing them before closing the base. The screen cradle withdraws 2 mm rearward and then down with the tray removed; unplug J6 before that motion.

Do a hot enclosed run at normal full speed and the highest commissioned boost, followed by the simultaneous peak-load test. Record input current, rail minima and component/sensor temperatures. Verify the base can reject regulator heat after a fan stall. A firmware temperature reading alone does not establish the hottest component temperature.

During cleaning, unplug USB, wait for the rotor to stop and reservoirs to discharge, then remove the magnetic grille. The grille sensor stops commanded loads but cannot stop a rotor instantaneously. Avoid pulling modules by their wires or pressure tubes. The internal micro-B connector remains available for recovery; the HUSB238 data pads are not connected in E3.

## Record before calling the electronics complete

Record the carrier PCB revision/gerber hash, final populated BOM, photos of polarity-sensitive parts, continuity/ERC/DRC results, oscilloscope startup/shutdown traces, calibrated divider gains and servo tables, observed peak/continuous current, hot-case temperatures and every fault-test outcome. All of these physical results are currently pending; software simulation and analytical calculations do not replace them.

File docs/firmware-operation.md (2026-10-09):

# Firmware operation and validation

The firmware targets the **Raspberry Pi Pico SC0915 / RP2040**, Arduino-Pico core **6.1.0**, and Adafruit NeoPixel **1.15.2**, Adafruit **ST7735 and ST7789 Library 1.11.0**, **GFX 1.12.6** and **BusIO 1.17.4** for the SPI IPS screen. The E3 source and current UF2 have passed host checks and the Pico build described below; this remains software verification without an attached physical device. It is a commissioned-prototype controller, not a claim of tested physical hardware. Initial settings are deliberately uncommissioned: the fan and servo stay disabled until calibration is completed and saved. Build scripts do not flash a board automatically.

## Building

In PowerShell:

```powershell
cd C:\Users\admin\iCloudDrive\Windflow
.\tools\setup_arduino.ps1
.\tools\test_firmware.ps1
.\tools\build_firmware.ps1
```

The setup script installs isolated dependencies under `.tools`. The board build selects `rp2040:rp2040:rpipico:flash=2097152_262144,freq=133`. Its output is `firmware/dist/Windflow.ino.uf2`. Load it by the Pico's BOOTSEL procedure only after identifying the physical board and checking the wiring. The host tests require the project's `.tools/venv` Python environment with `ziglang`; that environment is separate from the Arduino setup script.

## Modules and timing

| Module | Responsibility |
|---|---|
| `Config.h`, `Control.*` | Validated settings, geometry mapping, timed operating states and safety priorities |
| `Hardware.*`, `SensorCodec.h` | PWM, tach capture, ADCs, I2C transactions and sensor checks |
| `Input.h`, rotary-control state | Quadrature decoding, debounce, button gestures, relative angle and deliberate 360 degree boost-entry turn |
| `Lighting.*` | Downward ambient chain and bounded service pixel tests |
| `Display.*`, `DisplayView.*`, `DisplayLayout.*` |320 x240 landscape display, reserved top status/speed area, relative encoder dial and boost-entry countdown |
| `Service.*`, `Calibration.h` | Bounded USB command parser and session calibration evidence |
| `Storage.*`, `SettingsRecord.h` | Two alternating filesystem records, CRC and validation |
| `Windflow.ino` | Boot/service gate, cooperative scheduling, delayed saves and watchdog |

The control tick is 10 ms; ambient LEDs refresh approximately every 33 ms. The screen renders into one 320 x16 RGB565 buffer (10,240 bytes), rather than allocating a full screen framebuffer. Each strip has 3.41 ms raw wire time at 24 MHz; the 15 strips use at least 6 ms between transfers, with control/sensor polling between strips and approximately 10 Hz page updates. The reserved header remains 64 pixels high. Drawing overhead and actual maximum control-loop delay still need measurement; raw wire-time arithmetic does not prove real-time timing. I2C runs at 100 kHz with 2 ms transaction timeouts. Voltage/position inputs update every 10 ms, pressure every 20 ms, PD status every 100 ms, and both temperature sensors every 150 ms. Each loop processes at most 24 incoming USB characters. No startup animation uses a blocking delay. The one-second watchdog resets the MCU if the loop stops progressing; a watchdog reset latches a fault on the following boot.

GP6 generates **25 kHz** fan PWM through an inverting open-drain transistor. GP8 uses a different RP2040 PWM slice for **50 Hz** servo pulses. Signal levels are set before loads are enabled. Hardware enable pulldowns keep all switched loads off during reset. The cosmetic LED rail has a **50 ms** settling interval before data is sent, matching the specified 100 nF load-switch slew capacitor.

## User controls and deliberate boost entry

The encoder is a 24-detent Bourns PEC11H. Set `encoderReverse` so moving the exposed wheel upward increases output. A short release toggles on/off. Holding **1.2 seconds** toggles night mode without generating a short press; push debounce is 25 ms. The mechanical encoder rotates continuously, so the screen shows a **relative angular position since boot**, with 15 degrees per detent and wrap at 360 degrees. It is not an absolute shaft-angle sensor.

The normal and boost controls now have a deliberate separation requested by the user:

1. In normal control, rotation raises fan power from 0 to 100% while keeping both nozzle panels fully open. **24 physical detents, one revolution, cover the entire normal range**, independent of the configured internal endpoint. The default stored normal segment is 0–750; the controller maps 25 positions to rounded values on that segment. Normal power changes by approximately 4.17 percentage points per detent. An arbitrary saved/service value stays unchanged until rotation, then moves to the strictly adjacent grid point in the chosen direction. At stored 400, for example, upward rotation selects 406 and downward selects 375.
2. At normal 100%, continue upward for **one complete revolution: 24 detents /360 degrees**. This is the boost-entry turn. The fan remains at its maximum allowed PWM and the panels stay fully open. The screen counts down the remaining degrees/detents. The detent that completes this entry turn does **not** close the panels.
3. Subsequent upward rotation controls progressive boost over a further 24 detents. The fan remains at maximum allowed PWM; the outlet area decreases smoothly from 100% to the calibrated minimum, initially 75%. The screen switches to a distinct purple boost indication and shows commanded boost percentage.
4. Rotate downward to reduce boost. Reaching zero closure leaves boost control at normal 100%, fully open, and clears the entry counter. A fresh 24-detent /360 degree entry turn is required before every later boost session. Downward rotation during a partly completed entry turn first unwinds that progress; further downward rotation reduces normal power.

Entry is accepted only in Live operation with the fan on, at normal maximum, the nozzle open, and no thermal/boost limitation. Startup, off, service and fault states cannot queue an entry turn. Turning off cancels boost and entry progress. A saved boost setting is restored as **normal maximum with the nozzle open**, requiring the deliberate entry turn again after power-up. Safety opening takes priority over the displayed command; a limited boost condition is clearly indicated.

Internally, `boostThreshold` retains the stored-setting split for compatibility with geometry and calibration; it no longer causes entry merely by crossing a normal percentage. With normal fraction `n`, requested boost fraction `b`, minimum stable PWM `pmin=0.20`, maximum permitted PWM `pmax=1.00`, and minimum area ratio `rmin=0.75`:

| Control state | Fan target | Nozzle target |
|---|---|---|
| Off or normal zero | Supply disabled | Opens while servo supply is healthy |
| Normal 0–100% | `pmin + (pmax-pmin)*n` for nonzero settings | Fully open |
| Boost-entry turn | `pmax` | Fully open |
| Boost control 0–100% | `pmax` | Area ratio `1-b*(1-rmin)` |

Panel angle is `asin(H*(1-areaRatio)/(2*L))`, with `H=94 mm`, `L=55 mm`. At the initial endpoint each panel rotates **12.3355 degrees** and retains 75% gross outlet area. Five measured servo pulse/feedback pairs interpolate equal panel-angle fractions. This is not a direct linear servo sweep. Closure remains bounded by a 15-degree geometric ceiling, the allowed area ratio is at least 0.75, and pulses must remain 900–2100 microseconds.

Closure advances at no more than 0.35 calibrated travel per second and opens at up to 1.2 per second. Live fan increases are slew limited to full duty per second; reductions are twice as fast. Off/zero disables the fan immediately. Pressure, thermal, servo and power protection override all user targets.

## Screen layout and night mode

The selected **Adafruit 4311 2 inch IPS screen** uses 320 x240 landscape pixels. The **top 64 rows are reserved** for the bars it replaces: normal power in blue/cyan, boost in purple, plus USB power, system/fault and night indicators. Text accompanies color so the operating mode is unambiguous. The lower 176 rows prioritize a large power percentage during normal use, the remaining angle during entry, and a large boost percentage in boost. They also show relative wheel position, measured RPM, worst monitored temperature, pressure and commanded outlet area. The outlet percentage is computed from the commanded panel position; it is not an independent measurement of open area. Below normal maximum the countdown includes the detents needed to reach maximum plus the complete entry turn; it identifies those two parts explicitly. At zero it shows 720 degrees, at stored 400 it shows 540, and at normal maximum it starts at 360; it reaches 0 only after the full entry turn. If entry is temporarily unavailable, the screen distinguishes opening the outlet, reaching full power and a safety restriction. Rejected turns are not queued for later entry.

The separate downward 8-pixel strip remains warm-white ambient lighting. Its default brightness is 12/255; default night ambient brightness is zero. Screen backlight uses the retained service key `mainBrightness` (default 60/255, maximum 80); night backlight uses `nightMain` (default 0, maximum 4). Their legacy names do not refer to physical main LEDs. `mainCount` is a reserved stored field fixed at 16 for compatibility and is not a service key; only the ambient strip has addressable pixels. Screen backlight uses 2 kHz PWM on GP16. Night mode suppresses unnecessary animation and greatly dims/disables the screen while leaving fan control active. An essential fault overrides night dimming with 36/255 backlight and remains visible while the 5 V logic rail is healthy. Service mode also uses at least 36/255 for calibration legibility; a thermal warning enforces at least 16/255 while ambient lighting is disabled. The screen is powered from REG2 and is independent of the switched ambient rail.

The selected pins are SPI0 MOSI=GP19, SCK=GP18, CS=GP20, D/C=GP10, RST=GP7, BL PWM=GP16. Backlight uses PWM slice 0, separate from fan slice 3 and servo slice 4. GPIO supplies control signals only; the screen/backlight is powered by the 5 V rail. BUF2 channels 1/2 buffer CS/reset; channel 3 buffers BL with the same active-high 2 kHz PWM. Its GP16-side R59=100k pulldown, R55=330 ohm output series and display-side R56=1k pulldown must be fitted. This external circuit correction needs no inversion or firmware pin change. Host tests do not establish physical darkness at night brightness zero or absence of a power/reset flash.

## Startup and saved settings

1. Initialize output signals with load supplies disabled, read settings, start sensors and the watchdog.
2. Require a stable **15 V / at least 2 A** PD contract, measured bus 14–16 V and logic rail 4.65–5.35 V for 500 ms.
3. Refuse automatic operation if settings are absent, invalid or uncommissioned.
4. Command fully open panels, keep the fan and decorative LEDs off, and check position feedback. Home requires 400 ms elapsed, feedback within 60 ADC counts of the open calibration, and good servo-regulator PG. Failure to reach home by 1.5 seconds latches a servo fault.
5. Enable the screen live/startup display and ambient lighting. Ramp fan duty from zero to configured `maxPwm` over **1.8 seconds** using a smoothstep curve. The speed indication in the reserved screen header fills in sync, with panels open.
6. Return smoothly toward the saved setting over **0.9 seconds**, still with panels open. A saved boost setting is clamped to normal maximum/open; closure needs a new deliberate 360 degree entry turn.

Night mode, a saved off/zero setting, thermal warning, or invalid pressure skips the full-speed animation. Pressure/thermal limits remain active during both ramps. An off/zero command cancels a ramp. This prevents a deliberately stopped fan from briefly starting at full power after reconnection.

Settings schema **3** adds the screen/input revision and rejects the earlier light-bar settings. The retained ADC isolation circuit uses default bus scale **11.1** and logic scale **2.1**. Schema-1 and schema-2 records are rejected and require recalibration. The analog feedback LUT must also be measured with the final divider circuit.

Settings use alternating `settings0.bin` / `settings1.bin` records with magic, schema, size, sequence and CRC32. A save writes the alternate slot, flushes it, then reads back and compares the entire record before declaring success. Loading chooses the newest valid record, including sequence rollover. The filesystem does not automatically format itself on failure.

Normal changes save only in Live state, with the servo near its feedback target, healthy PD and bus at least 14.5 V, **8 seconds after the last change** and **at least 60 seconds between attempts**. Thus a power loss immediately after adjustment can restore the previous setting. Calibration saves explicitly after validation. Two records and CRC provide corruption detection and fallback; actual brownout behavior and filesystem recovery still require power-cut tests on hardware.

## Safety behavior

| Condition | Detection and action |
|---|---|
| Fan stall | Two tach pulses per revolution; discard pulse intervals below 1.5 ms, treat feedback older than 600 ms as zero. After 2.4 seconds of fan startup grace, duty at least 30% with RPM below `max(250, 0.30 * rpmAtMax * duty)` for 800 ms latches a stall fault. |
| Abnormal full-speed RPM | In Live state near maximum duty, after 3.5 seconds of fan operation: RPM below 70% or above 125% of measured baseline for 800 ms disables boost; after 4 seconds it latches a stall fault. |
| Excessive pressure | Default pressure above 18 Pa progressively reduces the allowed closure. Above 24 Pa forces opening and caps duty at 40%; persistence over 1.2 seconds latches a pressure fault. Limits are applied to pressure after subtracting calibrated zero. |
| Pressure missing/reversed | Invalid CRC/scale, stale reading over 100 ms, non-finite data or differential pressure below -2 Pa opens the nozzle and caps duty at 50%. Stale continuous-mode measurements trigger a bounded sensor stop/start retry after about one second. |
| Servo tracking | Feedback error over 90 ADC counts or bad servo PG, after a 600 ms state settling allowance, for over 650 ms latches a servo fault. Fault disables the fan and servo so the motor is not repeatedly driven into a stop. |
| Thermal warning | Either sensor at 55 C: opens nozzle, disables cosmetic lighting and caps duty at 50%. Warning clears only below 50 C. These thresholds are configurable within validated bounds. |
| Severe heat / missing temperature | Either sensor at 65 C, invalid temperature data or readings stale over 400 ms: latch a fault and disconnect fan, servo and cosmetic lighting. |
| Power fault | Lost/insufficient PD contract, bus outside 14–16 V or logic outside 4.65–5.35 V latches a fault. Fan PG must be high after 300 ms of enable; servo PG is also checked. No high-current load is driven by a GPIO. |
| Guard removal | Open guard switch latches a fault and removes all switched loads. |
| Watchdog reset | Latches a fault at boot; automatic fan startup is suppressed. |

Boost limits remain latched until the control is returned to the normal segment; reopening alone does not automatically reapply constriction. The screen header explicitly identifies waiting, service, uncommissioned, limited boost and faults. Fault indication overrides night mode and cosmetic animation. Leaving boost requires a fresh 360 degree entry turn before another boost session.

Faults require `ack` over USB or a short encoder press. Acknowledgment requires good PD, correct measured rails, valid cool temperatures and the guard fitted; it restarts with the fan **off**. If the original problem persists, the next operating checks can latch the fault again. There is no automatic repeated restart into a stall.

RPM does **not** measure airflow on the selected speed-regulated Noctua fan; a restriction can preserve RPM. The differential-pressure sensor provides an independent restriction signal, but blocked/disconnected tubing that produces plausible readings is not fully diagnosable. Pressure tap placement and thresholds require measurement. The servo does not spring open when unpowered; a severe fault disconnects the fan rather than assuming an open nozzle. No current sensor is fitted: branch fuses, voltage supervision, position feedback and time limits complement one another but do not measure winding current.

## Validation evidence and remaining physical checks

The current E3 host suite passes **41,311 control/encoder assertions**, **185 display-view assertions** and **227 production service-command assertions**, with exit 0 for all three programs. It compiles the production control logic, calibration evidence, settings records, sensor decoders and service commands. Checks cover the one-turn normal range, deliberate 24-detent boost-entry turn, progressive boost, reversal/re-entry, cancellation, saved-boost restart, screen data, cosmetic calibration retention and safety priorities. The exact production Adafruit_GFX layout also passes **384,000 pixel comparisons**, with exit 0. That comparison verifies that the 16-pixel strip renderer reproduces the complete 320 x240 scenes; it is not a test of the physical TFT, its wiring or SPI timing.

The final Pico compilation passes with exit 0: **121,460 bytes of program storage and 11,112 bytes of static RAM**. The canvas additionally allocates **10,240 bytes from the heap**; the static-RAM figure does not include that allocation or all runtime stack/heap use. The current build uses the pinned libraries listed above. No UF2 has been flashed and no physical fan, servo, sensor or screen has been commissioned.

Host/build checks do not exercise I2C/SPI wiring, real USB framing, flash power loss, analog noise, actual PWM/rail timing or actuator behavior. Hardware release still requires scope checks of PWM and rail sequencing, measured voltage scaling, tach comparison with an independent tachometer, temperature-sensor reference checks, safe obstruction/pressure tests, servo jam/current/torque tests, screen/ambient/input checks, repeated power-cut storage tests and the airflow/noise/temperature procedure in [calibration.md](calibration.md). Measure maximum control-loop gaps during screen refresh and confirm full-turn entry/reversal/re-entry on the actual encoder. Rendered previews and raw SPI wire-time calculations do not prove readable brightness, absence of reset flashes or real-time responsiveness.

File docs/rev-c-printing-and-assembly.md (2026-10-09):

# Rev C printing, assembly and service — 8 October 2026

This document applies to the P2406 motor/ESC design in `cad/rev_c/`. Use the current source-matched head, rotor and motion reports. Rev B's Noctua mount, 12 V power branch and 76-instance Onshape clearance report do not qualify this design. The printed impeller is a guarded development article; the distributed firmware cannot command rotor motion.

## Parts and process

| Parts | Starting material / orientation | Process and inspection |
|---|---|---|
| Left/right flowing head with integral outlet | Dry PETG; split X face on bed | 0.2 mm layers, 0.4 mm nozzle, at least four walls. Check seam bosses, outboard bearing/guide supports, inlet bead and carrier seats in the slicer. Local supports may be required; remove them before assembly. Do not leave support fragments in the air path. |
| Base shell | PETG, open bottom toward bed | 0.2 mm layers, four walls. The roof and internal pillars need an inspected bridging/support plan. Print a side/control coupon first. Rear vents must remain open; remove supports through the service opening. |
| Bottom tray, display cradle, bezel and covers | PETG, broad flat face toward bed | Use four walls; small nut/insert lands should be solid. Protect the screen glass from insert-installation heat. Keep screw access and actual EYESPI pigtail clearance. |
| Panels, cranks, yoke and rod | PETG, tested mechanism coupon orientations | Keep 1.6 mm panel skins fully resolved. Print crank/yoke/rod on broad X faces. Test bridge sag in hinge bores and ream only after measuring. Use metal smooth sleeves; threads do not bear on printed pivots. |
| Stator and guards | PETG, axial face toward bed where feasible | Seven default vanes are 1.2 mm thick. Guard clear slots are nominally 4.8 mm. Inspect extrusion continuity along long bars and supports. The guards are not certified fragment containment. |
| Carrier isolation ring, wire liner and desk feet | TPU 95A, separately printed | Measure seat compression, concentricity and creep. Rigid carrier alignment must remain stable. The four feet sit below the tray, giving downward lighting actual desk clearance. |
| Ambient diffuser | Translucent PETG, flat | Start at 0.8 mm thickness. Inspect hot spots and glare using the actual LEDs; the screw-on keeper permits replacement. |
| Impeller and shaft coupon | Follow [impeller process](rev-c-impeller.md) exactly | The rotor needs a separate qualified print and guarded balance/spin program. A dimensionally valid STL is not permission to operate it. |

The carrier uses a 0.8 mm radial TPU sleeve and 0.4 mm axial lips. Four rigid alignment stops have a nominal 0.3 mm gap; test compression and runout before fitting a rotor. Other starting fits include 0.3 mm sliding-guide clearance, 0.35 mm per panel side, 3.3 mm bores for 3 mm hinge shafts, and 6.55 mm magnet pockets for 6.35 mm discs. Use the thirteen [Rev C test pieces](../cad/rev_c/testpieces/testpiece-validation.json), including a pair of 6° aiming rails, with the actual printer, filament and orientation. Inspect the small upper LED support necks before tightening; screw loads should seat the board without touching LED packages.

Use [service-interface datums](../cad/rev_c/service-interfaces.json) for exact nominal axes. Six shell seam positions use M3 screws and RX-M3x5.7 inserts. Display and linkage-cover screws enter from accessible faces. All inserts and captive nuts must be installed before closing the corresponding shell. Pilot diameters are starting values rather than guaranteed press fits.

## Assembly sequence

1. Inspect the purchased motor, ESC, encoder, feedback servo and current-revision screen. Measure the motor prop seat, thread pitch/hand, usable thread length and permissible M3 insertion depth. Resolve the 8/10 mm shaft-drawing discrepancy before choosing the final rotor clamping stack. Verify the exact A50S V2.3c connectors; its vendor V2.2 reference is historical.
2. Print and inspect the shaft/clamping, hinge, yoke slot, encoder, insert, magnet/diffuser and carrier-fit coupons. Check a print of the curved fascia before printing the full enclosure. Install inserts, captive nuts and magnet-retaining hardware with the components removed.
3. With the head split open, place the rounded inlet spigot/bead in its captive seat. Fit the rear finger guard with four M2×10 through-bolts, ISO 7089 washers and ISO 4032 nuts; capture the nuts before closing the head. Mount the motor rigidly on the Ø16 mm pitch-circle carrier with four M3 screws of a measured safe length. Fit the replaceable TPU carrier ring and place the assembly in its captured seat. Check alignment without the rotor installed.
4. Place the independently removable stator in its locating seat. Its trial geometry must later be compared with an open spacer; straight vanes are not a qualified swirl-recovery design. Fit the fixed front guard and verify its screw access.
5. Assemble the guide/yoke and separate keyed cranks, then the two panels. Close the structural head around the inlet, carrier and stator. Insert both nominal 172 mm ground-steel hinge shafts from the left; fit the separately placed collars and spacers. Deburr and verify shaft length against the supplied hardware before cutting.
6. Fit the four sleeved M2 pivot stacks, connecting rod and the supplied servo horn. Fit the adjustable FS90-FB bracket, set the real output datum and manually sweep the full linkage. Fit neither endpoint by driving the servo against a stop. Keep the loom outside the entire yoke/crank envelope. Secure the curved cover using its four accessible M3 locations after commissioning checks.
7. Install the Omron D2F-01L on its slotted bracket, its protected raceway and TPU wire clamp. Adjust the grille's integral tongue to trip reliably with bounded overtravel. The case/lever drawing does not establish the actual switch trip point. COM goes to ground, NO to the buffered guard input; insulate NC. Verify electrical opening on grille removal before connecting the motor branch.
8. Mark magnet polarity before insertion: all head outward faces share one pole; grille inward faces attract them. Install four D42 discs per side, using the allowed adhesive clearance and the screw-on retaining rings. Keep magnets away from hot insert tooling. Test deliberate peeling and maximum-operation retention/rattle on the actual assembly.
9. Fit the clear screen lens and bezel, then the LCD to its two genuine PCB mounting holes on the removable cradle. Fit the four rear cradle screws. Support the PCB and mounting tabs; do not clamp the glass. Install the horizontal encoder through its nut-supported bracket and its separately supported routed daughterboard. Check switch travel and wheel-to-shroud clearance by hand.
10. Populate the removable tray with the Pico, two 5 V regulators, PD sink, sensors, ambient stick and ESC cradle. The nominal stacks use M1.6×12 for the Pico, M2×14 for the regulator/PD boards and M1.6×8 for the ambient stick. Use the documented board-hole datums and check the small clearance beside the LED packages. The protected circuit is captured in the [editable KiCad schematic](../hardware/pcb/rev_c/windflow-rev-c.kicad_sch); its 80 × 55 mm main PCB still needs placement/routing and electrical checks before fabrication. Fit the actual ESC with a nonconducting restraint and free connector access.
11. Route the three phase leads separately from short UART/ground and analog/I2C wiring. Fit strain relief at connectors and the servo exit. Provide slack for unplugging the tray, screen and servo. Pressure hoses need a new source-matched route with correct bend radius and independent housing restraint; do not copy the old Noctua layout unchanged.
12. Fit the downward diffuser and its removable keeper. Fit the tray and four TPU feet. Connect only the specified 15 V / 3 A PD supply. Test housekeeping, display, night mode, switch input, sensors, branch gates and servo with the rotor absent. Commission the motor and rotor only under the separate contained test plan.

## Service paths

For routine cleaning, disconnect power, verify rotor rest, then peel off the magnetic grille. Fixed guards remain in place. Removing the cosmetic grille interrupts torque permission but does not stop mechanical coast instantly. Removing a fixed guard is a service operation with power disconnected and rotor rest confirmed.

The screen, with its cradle attached, withdraws rearward 4 mm and then lowers 70 mm through the open bottom after the bezel/lens, tray and loom are removed. The motion report checks that nominal unplugged path. It does not model a live connected harness or screwdriver.

To service the tray, disconnect USB-C and wait for discharge/rest, remove the foot/tray fasteners, unplug the board-to-head and screen looms, then lower the tray. The PD board is recessed at the rear port; the actual plug and cable must be checked. Release the ESC restraint before unplugging its miniature I/O connector; pull connector housings rather than wires.

## Qualification boundaries

Nominal rigid-solid clearance checks can resolve known CAD collisions. They do not qualify print error, deflection, heat creep, rotor runout/balance, switch overtravel, magnet holding force, connector fit, dynamic hose/wire motion or an installed tool path. Those are measured acceptance items. Airflow/noise/power, low-speed FOC compatibility, boost usefulness and an unattended-use speed ceiling remain unmeasured. Main-board routing, pressure plumbing, installed looms and complete fastener/tool checks remain design work. The complete development geometry is imported into Onshape alongside the native parametric architecture; the [checkpoint record](../cad/onshape-rev-c-checkpoint.json) identifies the exact checked files and limitations.

## Front encoder revision

The8October mount sits beside the screen. Its shaft is horizontal +Y and its disk turns parallel to the screen face. Print the source-matched front encoder wheel, bracket and fascia section before the complete base. Assemble captiveM2nuts, PCB and Bourns bushing/nut first; attach the bracket using its separate M3axes; install the wheel last. Remove the wheel before bracket service. See [front controls](rev-c-front-controls.md) for the gesture and test limits.

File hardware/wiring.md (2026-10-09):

# Wiring and pin assignments — electrical revision E3

**Rev B historical wiring.** Use the [Rev C power and wiring specification](../docs/rev-c-motor-power.md) and [Rev C firmware pin mapping](../docs/rev-c-firmware.md) for the P2406 motor and A50S ESC. The four-wire fan circuitry below is superseded; ESC UART, branch power gating and a 15 V / 3 A PD contract require a revised carrier. Do not connect the new motor to this earlier fan circuit.

This is the prototype's net-level circuit specification, updated 2026-10-05 with the 5 V grille-contact circuit and 3.3 V BUF4 output. It corresponds to firmware defaults `busScale=11.1`, `logicScale=2.1` and a 50 ms LED rail-settle interval. It is **not a routed PCB, an ERC report, or a bench-tested circuit**. Build the carrier described in [electronics assembly](../docs/electronics-assembly.md) before enclosure integration.

## Power diagram

```mermaid
flowchart LR
  P[USB-C PD source 15 V / 2 A] --> H[Adafruit HUSB238 5807]
  H --> F[F1 2 A and D1 TVS]
  F --> E[EF1 input eFuse / controlled inrush]
  E --> B[Protected DC bus]
  B --> R1[REG1 12 V]
  B --> R2[REG2 5 V logic / LED]
  B --> R3[REG3 5 V servo]
  R1 --> S1[F2 and SW1]
  S1 --> FAN[Fan]
  R3 --> S2[F3 and SW2]
  S2 --> SER[Servo and BUF3]
  R2 --> S3[SW3]
  S3 --> LED[8 ambient pixels and BUF1]
  R2 --> D2[SS14]
  D2 --> MCU[Pico VSYS]
  R2 --> TFT[ST7789 screen and BUF2 CS/reset/backlight]
  MCU --> V3[3.3 V sensors and ADC isolation]
```

J1 PD+ goes through F1 to `RAW_FUSED`; D1 SMBJ18A cathode goes there, anode to system GND. C1=100 nF goes across this raw input. **No 100 uF reservoir is connected directly to raw USB VBUS.** EF1 feeds `BUS_PROTECTED`, with C2=100 uF and REG1/2/3 inputs. This places bulk capacitance behind controlled slew. The HUSB238 itself negotiates 15 V without requiring the Pico to be running. Unsupported low-voltage sources can leave the unit dark; a live status display is not promised without housekeeping power.

REG1 is D24V22F12; REG2 and REG3 are D24V22F5. Each has VIN to protected bus and GND to system GND. Leave module EN unconnected: its onboard pullup is to input voltage and **must not connect directly to a Pico GPIO**. REG1 PG goes to GP22; REG3 PG to GP21; REG2 PG is unused. C3/4/5=1 uF at the three input connections. C6/7/8=100 uF at REG1/2/3 outputs. REG2 feeds Pico VSYS pin 39 through D2 (anode REG2, cathode VSYS); no external connection to Pico VBUS in the installed power circuit.

F2=0.5 A goes between REG1 output and SW1 VIN. F3=1 A goes between REG3 output and SW2 VIN. SW3 VIN is REG2 output. Fuses protect branch wiring; a 1 A fuse will not reliably interrupt a 0.6 A servo stall, which is handled by feedback and timed cutoff.

## Input eFuse EF1

Use **TPS26600PWPR**, HTSSOP16. Pin 1 and 2 IN=`RAW_FUSED`; pin 15 and 16 OUT=`BUS_PROTECTED`; pin 9 GND=system GND. Pin 8 RTN and exposed thermal pad form a **local RTN island**, distinct from system ground. Reference the following control parts to this island. Do not silently join RTN to GND: that defeats the chip's reverse-polarity arrangement.

R44=100k from IN to pin 3 UVLO, R45=15k from UVLO to RTN. Also connect pin 7 SHDN to this UVLO node (at 15 V it is about 1.96 V, within SHDN's 0–4 V recommended range). This yields roughly 9.12 V rising UVLO and 8.43 V falling UVLO; firmware still requires the proper 15 V contract. R46=130k from IN to pin 5 OVP, R47=10k from OVP to RTN: nominal rising OVP16.66 V. R42=8.06k pin 11 ILIM to RTN sets approximately 1.49 A. R43=402k pin 6 MODE to RTN selects active limiting followed by latch-off if the eFuse overheats. C29=100 nF pin 12 dVdT to RTN controls initial ramp. Pin 10 IMON and 14 FLT are unconnected; pin 4 and 13 NC remain unconnected. A power disconnect resets a latched eFuse; firmware cannot clear it. All values are design choices requiring tolerance/bench verification against the [TI data sheet](https://www.ti.com/lit/ds/symlink/tps2660.pdf).

## Pico physical pins

| GPIO | Physical pin | Net and interface |
|---|---:|---|
| GP0 | 1 | Encoder A, R1=10k to 3.3 V, C26=10 nF toGND |
| GP1 | 2 | Encoder B, R2=10k, C27=10 nF |
| GP2 | 4 | Encoder push, R3=10k, C28=10 nF; contacts close toGND |
| GP3 | 5 | Fan tach, R4=4.7k to 3.3 V; two pulses/rev |
| GP4 | 6 | I2C0 SDA, optional R6=4.7k to 3.3 V |
| GP5 | 7 | I2C0 SCL, optional R7=4.7k to 3.3 V |
| GP6 | 9 | 25 kHz fan PWM through R13=100 ohm to Q1 gate |
| GP8 | 11 | 50 Hz servo PWM through BUF3, noninverting |
| GP7 | 10 | TFT RST via BUF2 channel 2, R54=33 ohm; R58=10k input pullup to 3.3 V |
| GP10 | 14 | TFT D/C through R53=33 ohm |
| GP11 | 15 | Ambient data via BUF1 channel 2 and R16=330 ohm |
| GP12 | 16 | SW1 EN, R10=100k pulldown |
| GP13 | 17 | SW2 EN, R11=100k pulldown |
| GP14 | 19 | SW3 EN, R12=100k pulldown |
| GP15 | 20 | Guard present via BUF4 3.3 V output; R60=100k to3.3 V. Installed grille closes the separate5 V contact node toCOM/GND |
| GP17 | 22 | Service jumper toGND; internal pullup |
| GP16 | 21 | TFT BL PWM via BUF2 channel 3, then R55=330 ohm; R59=100k GPIO-side pulldown, R56=1k to GND at display end |
| GP18 | 24 | SPI0 SCK through R51=33 ohm |
| GP19 | 25 | SPI0 MOSI through R50=33 ohm |
| GP20 | 26 | TFT CS via BUF2 channel 1, R52=33 ohm; R57=10k input pullup to 3.3 V |
| GP21 | 27 | REG3 PG, R8=4.7k to 3.3 V, high-good |
| GP22 | 29 | REG1 PG, R9=4.7k to 3.3 V, high-good |
| GP26 / ADC0 | 31 | Protected bus divider via ISO1, scale 11.1 |
| GP27 / ADC1 | 32 | Servo feedback divider via ISO1; calibrate raw five-point table |
| GP28 / ADC2 | 34 | REG2 monitor divider via ISO1, scale 2.1 |
| 3V3 OUT | 36 | Sensors, input pullups, ISO1, SUP1 |
| VSYS | 39 | D2 cathode only; REG2 is the anode source |
| GND / AGND | 3, 8, 13, 18, 23, 28, 33, 38 | Common circuit ground; high-current returns bypass MCU and ADC paths |

GP6 fan, GP8 servo and GP16 backlight occupy distinct RP2040 PWM slices (3, 4, 0 respectively). GP7 is a digital reset output, not a PWM backlight output; putting the backlight on GP7 would change the fan slice frequency. Preserve this separation when changing pins. No 5 V signal is connected directly to a Pico GPIO.

## Output drivers and default-off behavior

SW1/2/3 are **TPS22810DBVR**, with pin 1 VIN, pin 2 GND, pin 3 EN, pin 4 CT, pin 5 QOD and pin 6 VOUT. C11/12/13=1 uF from each VIN toGND; C14/15/16=100 nF from corresponding CT toGND. R39/40/41=330 ohm, 1206 0.25 W, connect QOD to its VOUT. Do not substitute a wire on the 470 uF branches. C9=470 uF goes across SW2 output and C10=470 uF across SW3 output. EN pulldowns are mandatory. The 100 nF CT is intentional: 10 nF made calculated capacitor inrush alone about 2.19 A. Servo/LED supply discharge is finite; do not infer an instant zero voltage from EN low. The [TI switch data sheet](https://www.ti.com/lit/ds/symlink/tps22810.pdf) governs layout and QOD sizing.

BUF1 and BUF2 are **74AHCT125D,118**. Pin 14 VCC and pin 7 GND; C17/C18=100 nF locally. BUF1 VCC is switched ambient 5 V. Ambient uses A5/Y6/OE4 with OE4=GND, R19=100k on A5 and R16=330 ohm in the data output. Unused A2/A9/A12 go toGND, OE1/OE10/OE13 toVCC, Y3/Y8/Y11 unconnected. The former main LED channel is removed.

BUF2 VCC is unswitched REG2. TFT CS uses A2=GP20, Y3 through R52=33 ohm to display CS, OE1=GND; TFT reset uses A5=GP7, Y6 through R54=33 ohm to display RST, OE4=GND. R57/R58=10k pull the corresponding **GPIO-side A inputs** to 3.3 V. Backlight uses A9=GP16, Y8 through R55=330 ohm to display BL, OE10=GND; new R59=100k pulls A9 to GND. Only channel 4 is unused: A12=GND, OE13=VCC, Y11 unconnected. This reuses the former status buffer as three noninverting outputs, preserving active-high 2 kHz backlight PWM. The display's current EYESPI schematic pulls CS and RST to **VIN through onboard 10k resistors**: connecting these two pins directly to a Pico GPIO with VIN=5 V would exceed the GPIO voltage limit during reset. Keep the selected buffer's input-at-zero-supply specification. [Manufacturer schematic](https://github.com/adafruit/Adafruit-2.0-inch-240x320-TFT-PCB/blob/master/Adafruit%20EYESPI%202.0%20Inch%20240x320%20IPS%20TFT.sch), [buffer pinout and electrical limits](https://assets.nexperia.com/documents/data-sheet/74AHC_AHCT125.pdf).

DISP1 **Adafruit 4311** VIN=unswitched REG2, GND=systemGND. C30=1 uF at VIN. GP19/MOSI, GP18/SCK and GP10/D/C go through R50/R51/R53=33 ohm at their driver ends; these inputs use the onboard 3.3 V level converter and have no onboard 5 V pullup. GP16 drives BL through BUF2 channel 3 and R55=330 ohm; it does not supply the BL pulldown current directly. R56=1k BL-to-GND is fitted at the display end. The onboard BL 10k pullup is to regulated 3.3 V and drives an onboard BSS138 gate. Adafruit specifies 3–5 V logic at BL, so the noninverting 5 V buffer is appropriate. With nominal rails/resistors and ideal buffer levels, the gate is **3.748 V HIGH, 0.0799 V LOW**, and **0.300 V** if the buffer output/harness is disconnected. During Pico reset R59 holds the buffer input low; do not describe the disconnected figure as the normal powered-reset level. These are resistor-network calculations, not measured gate voltages. Applying the buffer's conservative 0.44 V maximum VOL at −40 to +85 C gives about 0.403 V at the gate; verify absence of visible night/reset light and adequate HIGH drive across actual rail, temperature and module tolerances. The exact fitted BSS138 manufacturer is not specified in the vendor schematic. The display stays powered when SW3 disables ambient lighting, allowing essential faults to remain visible while the logic rail is healthy. SDCS is left unconnected because its onboard 10k pullup deselects the unused card slot; MISO, 3Vo and EYESPI are unused. No microSD card is installed. [Pinout and PWM control](https://learn.adafruit.com/2-0-inch-320-x-240-color-ips-tft-display/pinouts).

Keep J6's SPI harness shorter than 150 mm, away from motor/servo leads, with a nearby ground return and strain relief. The 33 ohm values are starting damping values; verify edges and pixel errors at the final SPI rate rather than adding arbitrary capacitance. Do not connect display 3Vo to Pico 3V3 or parallel regulator outputs.

BUF3 is **74AHCT1G125GW,125**. Pin 5 VCC=SW2 output, pin 3 GND; C19=100 nF locally. Pin 1 OE=GND, pin 2 A=GP8 with R23=100k pulldown. Pin 4 Y goes through R17=330 ohm to servo signal; R24=100k pulls that signal toGND. A powered MCU can therefore command an unpowered buffer without an always-on 5 V signal driving the servo. Use the specified Nexperia parts: their input leakage is characterized at VCC=0; this is not a blanket property of every buffer family. [Quad data sheet](https://assets.nexperia.com/documents/data-sheet/74AHC_AHCT125.pdf), [single data sheet](https://assets.nexperia.com/documents/data-sheet/74AHC_AHCT1G125.pdf).

Q1 **2N7002,215**: gate 1 via R13, source 2 GND, drain 3 fan PWM. R14=100k gate-toGND. Firmware inverts PWM because Q1 high pulls fan PWM low; fan power is separately disconnected when off. Use the fan's internal PWM pullup; add no 12 V pullup. Fan plug pins 1/2/3/4 are GND/12 V/tach/PWM.

## Grille-present contact and logic level

The 5 October guard correction replaces the former R5=4.7k pullup to3.3 V. Omron lists a1 mA /5 V minimum applicable load as a reference for D2F-01 gold contacts; the previous0.70 mA /3.3 V circuit did not match that reference. R5 is now **3.9k1% from unswitched REG2 5 V to GUARD_CONTACT_5V**. J12pin2 carries that node to the NO contact, and COM returns through J12pin1 toGND. Installed grille therefore pulls the node LOW; unplugging the loom makes it HIGH. NC is unused.

**BUF4 SN74LVC1G17DBVR** translates this input: pin1 NC, pin2 A=GUARD_CONTACT_5V, pin3 GND, pin4 Y=GUARD_LOGIC_3V3 /GP15, pin5 VCC=Pico3V3. C31=100 nF locally across VCC/GND; C32=10 nF across the raw contact node/GND; R60=100k from GP15 to3V3. Keep the raw5 V net away from Pico pads. This exact buffer accepts input to5.5 V and specifies Ioff behavior during power-down; a generic buffer without those ratings is not a substitute. [TI pinout and limits](https://www.ti.com/lit/ds/symlink/sn74lvc1g17.pdf).

Closed-contact current is1.282 mA nominal at5 V; allowing the4.65–5.35 V qualified rail and1% resistance gives approximately1.18–1.39 mA. The39 us nominal RC filters short interference; it does not replace software state qualification or prove switch life. Omron's load value is a reference, not a guarantee for every environment: verify voltage, contact resistance, repeated removal, dust and temperature on the actual switch. With service USB powering the Pico but REG2 absent, the contact node can read LOW; the independent PD, bus and regulator-good gates must remain effective so this condition cannot enable actuators. The fixed inner guard remains necessary, including during rotor coast and a contact/wiring fault.

## ADC isolation and divider values

ISO1 **TMUX1511PWR**: pin 14 VDD=3.3 V, pin 7 GND, C20=100 nF locally. Channel 1 S2/D3 is bus; channel 2 S5/D6 servo feedback; channel 3 S9/D8 logic. SEL pins 1/4/10 join `ADC_ENABLE`. Unused channel 4 SEL13, S12 and D11 go toGND. SUP1 **TPS3808G33DBVR** pin 6 VDD and pin 5 SENSE=3.3 V, pin 2 GND, C21=100 nF locally; pin 3 MR=3.3 V; pin 4 CT unconnected. Pin 1 /RESET=`ADC_ENABLE`, R37=10k to 3.3 V and R38=100k toGND. No connection to Pico RUN is required. /RESET high means isolation channels on.

| Channel | Upper resistor / source | Lower resistor toGND at ISO1 S pin | Filter at S pin | ADC-side pulldown at D pin | Nominal scale |
|---|---|---|---|---|---|
| Bus | R28=100k from protected bus | R29=10k | C23=100 nF | R30=1M | 1+100k/(10k parallel 1M)=11.1 |
| Feedback | R31=100k from servo feedback | R32=100k | C24=100 nF | R33=1M | 2.1, but firmware uses measured raw table |
| Logic | R34=100k from REG2 output | R35=100k | C25=100 nF | R36=1M | 2.1 |

Place the capacitors **before** ISO1, so stored charge is disconnected from ADC pins when 3.3 V falls. After the mux, only the 1M pulldown and short ADC trace are present. The servo divider presents about 191k load to its feedback wire instead of the previous 20k; verify it does not materially disturb the internal servo potentiometer. Normal 15 V bus gives 1.351 V at ADC0; 5 V logic gives 2.381 V at ADC2. Resistor tolerance, leakage, ADC reference error and servo pot impedance are covered by measured calibration, not mathematical ratios alone. [Isolator limits](https://www.ti.com/lit/ds/symlink/tmux1511.pdf), [supervisor behavior](https://www.ti.com/lit/ds/symlink/tps3808.pdf).

## I2C and connector schedule

Bus speed 100 kHz. TEMP1=0x18, TEMP2=0x19 with A0 tied to 3.3 V, SDP810=0x25, HUSB238=0x08. Power both temperature boards and SDP810 from 3.3 V. The HUSB238 receives its own power from USB; do not connect its PD voltage to a sensor VIN. Measure existing pullups before fitting R6/R7; target combined 2.2–4.7k to 3.3 V. Breakout revisions must not add a hidden 5 V pullup. C22=100 nF decouples the pressure sensor connector at its supply.

The following numbered positions define the **carrier header** nets; mark pin 1 on PCB and housing. Module ends are soldered to labeled pads with strain relief unless a native plug is listed. Verify continuity rather than infer wire colors.

| Connector | Positions in pin order | Destination |
|---|---|---|
| J1 XH2 | PD+, GND | HUSB238 output pads |
| J2 XH3 | GND, SDA, SCL | HUSB238 I2C pads |
| J3 Molex4 | GND, switched 12 V, tach, PWM | Original Noctua four-pin plug |
| J4 Samtec 3 | GND, switched 5 V, signal | Original FS90-FB plug; check brown/red/orange supplied harness |
| J5 Samtec 1 | feedback | Original separate servo feedback socket |
| J6 XH8 | VIN5 V, GND, MOSI, SCK, CS, D/C, RST, BL | Adafruit 4311 labeled solder pads; unswitched logic rail, buffered CS/RST |
| J7 XH3 | GND, switchedLED5 V, ambientDIN | Ambient stick |
| J8 XH4 | GND, A, B, push | Encoder daughterboard; C and second push contact toGND |
| J9 XH4 | GND, 3.3 V,SDA,SCL | TEMP1 |
| J10 XH4 | GND, 3.3 V,SDA,SCL | TEMP2 |
| J11 XH4 | GND, 3.3 V,SDA,SCL | SDP soldered daughterboard, 2 mm sensor pitch; sensor native pins 1/2/3/4=SCL/VDD/GND/SDA |
| J12 XH2 | GND, GUARD_CONTACT_5V | Omron COM/NO; NC unused. Pin2 feeds BUF4 input and never connects directly to GP15 |
| J14 Samtec 2 | GND,GP17 | Removable calibration jumper |

E3 retires J13 (RGB lamp) and the former main-pixel components: LED1/LED2, R15, R18, R20–22 and R25–27 are not fitted. Reference-designator gaps are intentional. BUF2 and C18 remain for TFT CS/reset/backlight. R56 is now 1k and R59=100k is added at the BL buffer input. J6 changes from 3 to 8 positions; an old main-LED harness must not be reused on the new display connector. The retired lamp is not an independent fallback indicator; essential faults use the screen while REG2 is healthy.

## USB service and routing

Set HUSB238 jumpers by cutting 5 V and 1 A, then closing 15 V and 2 A. Firmware reads the contract and measured bus before load enable. Use the specified 45 W supply or another documented source offering 15 V at at least 2 A. Never infer a PDO from the USB-C connector shape or wattage label.

Prototype recovery uses a USB-C-to-micro-B data cable to the Pico, with carrier disconnected for initial firmware loading. Powered calibration can use the PD wall supply and Pico data cable together: D2 and Pico's onboard USB diode prevent supply backfeed. Do not connect two USB data hosts. HUSB238 D+/D− pads are **not wired in E3**: the proposed single-socket USB route needs controlled-impedance PCB design and USB enumeration testing. The user-facing power socket is USB-C; the internal Pico recovery connector remains accessible. Disconnect J2 (PD I2C) when bench-running the Pico alone with PD board unpowered, until that board revision's unpowered-bus behavior has been verified.

Keep servo/LED/fan power pairs together, return high current to its regulator, join grounds on the carrier plane, and keep the EF1 RTN island separate. Keep ADC traces short and clear of switching nodes; do not split the ground plane beneath digital signal returns. Clamp the USB PCB near the receptacle. Preserve connector insertion room, service loops and strain relief, and keep wires/tubes outside all rotor and linkage sweeps. The removable grille switch complements a fixed inner guard; it does not justify access to a coasting rotor.

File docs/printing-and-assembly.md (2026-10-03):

# Printing and assembly — development build

This procedure describes the Rev B straight-through, single-fan design. It is a build sequence for the developing geometry, not authorization to print a finished product. The final outlet is part of the two structural head halves. The removable pieces are the front cleaning grille, internal comparison straightener, service covers and purchased components; do not substitute the separate nozzle study fixture for the product head.

Use this document with the [BOM](../hardware/BOM.md), [electronics assembly procedure](electronics-assembly.md), [calibration procedure](calibration.md) and [physical validation plan](physical-validation.md). The live [deliverable register](deliverable-status.md) records what has actually been completed. The carrier PCB, grille interlock mounting, linkage protection and some component restraints remain design/release dependencies until the corresponding artifacts are present and checked. Onshape integration is a separate deliverable; local STEP exports do not establish that it is complete.

## Choose the right files

`cad/parameters.json` defines the shared mechanical starting dimensions. `cad/build_prototypes.py`, `cad/build_head.py` and `cad/build_base.py` generate the geometry. The head uses millimetres, airflow along +Y, width along X and height along Z. The integrated assembly raises the head centre by the `head_center_height` parameter; do not manually apply that offset to individual printable parts.

| Artifact | Use |
|---|---|
| `cad/prototypes/validation.json` | Generated coupon/part list, mechanism motion checks and their stated limits. Read the report produced by the current source revision. |
| `cad/rev_b/validation.json` | Generated head parts and dimensional checks. |
| `cad/rev_b/base-validation.json` | Generated base parts, vendor placements, fastener locations and sampled service-tray/USB access checks. |
| `cad/rev_b/display-validation.json` | Display/cradle insertion and removal paths: rearward 2 mm, then downward through the service opening. |
| `cad/rev_b/display-fastener-validation.json` | Twelve ISO 4762 screw-head/rear-tip envelopes clear the installed base bodies; threads and complete driver/hand sweeps are excluded. |
| `cad/prototypes/display-coupons.json` | Screen fascia and M2 insert coupons generated from the current mount geometry. |
| `cad/rev_b/assembly-interference.json` | Whole-assembly findings for the stated pose and generated files. Resolve every unintended intersection before treating a build as released. |
| Individual `.stl` files named in current manifests | Custom printable parts. Orient each part in the slicer; installed coordinates are not print orientations. |
| `REF-*`, `*-vendor.step`, compression-limiter references and full STEP assemblies | Purchased-item geometry, simplified envelopes or inspection assemblies. Do not print them as replacements for real fans, motors, electronics, metal shafts or fasteners. |
| `nozzle-test-frame` | Independent fit/motion test fixture. Its existence does not make the final nozzle detachable. |

Old exports may remain in a development folder after a geometry change. Select parts from the fresh manifest, not every STL found in the directory. Final quantities, screw lengths and shaft cut lengths must be reconciled against the frozen assembly and BOM. A changed panel key, collar, fan pad or printed skin can invalidate a previously accepted fit coupon.

## Print coupons before large parts

Use the intended printer, dried material, nozzle, layer height and orientation. Label each coupon with its actual size and slicer profile. Measure the finished part after cooling, then test it with the actual purchased item. A nominal CAD diameter is not a measured printed bore.

| Coupon / part | Starting options and acceptance |
|---|---|
| `m3-insert-coupon` | 3.8 / 4.0 / 4.2 mm pilots for the selected RX-M3x5.7 inserts. Choose a fit that installs straight without splitting or bulging the wall and resists the intended screw clamp load. Record insertion temperature and depth. |
| `horizontal-hinge-bore-coupon` | 3.15 / 3.30 / 3.45 mm bores for a 3 mm metal shaft. Check horizontal bridge sag, free rotation and remaining wall strength. The shaft must slide through by hand after normal finishing. |
| `yoke-slot-width-coupon` | 3.2 / 3.4 / 3.6 mm slots for the smooth 3 mm sleeve. Check both travel directions with the real washer stack tightened. |
| `panel-key-clamp-coupon` with `boost-panel-keyed-crank` | Fit the shaft before gently clamping the split hub. Require no cracked key, no shaft binding and no detectable lost panel motion under the measured operating load. Recheck after cycling. |
| `sliding-yoke-coupon`, rod and crank | Check straightness, guide sliding, screw access and clamp-free pivots before assembling a full nozzle. |
| `servo-slotted-bracket` | Measure the actual FS90-FB shaft datum, lug spacing, body, cable exit and supplied horn. The present family-derived envelope is provisional. |
| `encoder-mount-coupon` and wheel variants | Check M7 bushing support and 0.05 / 0.15 / 0.25 mm D-shaft allowances. The 30 mm wheel must rotate without shroud contact and still transmit the encoder's axial push travel. |
| `magnet-pocket-coupon` and keeper | 6.45 / 6.55 / 6.65 mm pockets for 6.35 mm magnets. Test fit, adhesive space and keeper fastening. This coupon's floor is not the final grille magnet gap. |
| `led-channel-coupon` with 0.6 / 0.8 / 1.0 mm diffusers | Qualify the retained downward ambient stick only. Use the actual NeoPixel board revision and translucent filament. Check solder clearance, hot spots and light leakage. |
| `display-fascia-coupon` with `display-front-bezel` and `display-removable-cradle` | Dry-fit the actual Adafruit 4311 screen, its two PCB holes, header/EYESPI connector and pigtail. Check the 42.4 × 31.6 mm visible aperture clears the active image, and the clear window stays off the LCD. |
| `m2-display-insert-coupon-3p1-3p2-3p3` | Compare 3.1 / 3.2 / 3.3 mm pilots with RX-M2x4 inserts. Manufacturer starting pilot is 3.2 mm. Record the selected printed fit and insertion depth; final bosses have 1.4 mm nominal surrounding wall. |
| TPU fan pad/bushing and final `tpu-fan-pad-m3` | Older coupons include M4 options. Use the final M3 mount stack for qualification; check compression, alignment and creep with the metal limiter fitted. |

Also make slicer-cut samples from the current large geometry for the USB receptacle opening and tray fascia, grille magnet pair with both skins, one rear-guard mounting post, one head seam/insert joint and a short panel/hinge section. Preserve the original wall thickness and print orientation in these samples. These are additional test pieces to derive from the frozen model, not claims that individually named exports already exist.

## Material, slicing and finishing

Use characterised PETG for structural parts and TPU 95A for the designated pads, shim and feet. Use translucent PETG for diffusers. Follow the chosen filament's temperature and drying instructions and verify dimensional results on coupons. The enclosure's thermal test determines whether the selected material remains suitable; the firmware's sensor temperature is not a rating for every printed surface.

A useful first profile is a 0.4 mm nozzle with 0.20 mm layers, reduced to 0.12–0.16 mm where curved inlet finish or horizontal holes benefit. Start with four perimeters and five top/bottom layers on structural pieces, with moderate infill in thick bosses. Thin aerodynamic parts require explicit slicer inspection: a 0.8 mm vane should resolve as two continuous extrusion lines, and a 1.6 mm panel as a fully joined wall. Adjust extrusion width/perimeter strategy to the actual geometry instead of assuming a perimeter count guarantees the intended solid section. Keep seams and support scars off the inner inlet, panel faces and guide surfaces.

| Part family | Initial orientation and inspection |
|---|---|
| Head halves | Put the broad split face toward the bed, with each duct half open for support removal. Inspect bearing-arm and guide-tunnel layers individually; use only accessible local supports. Check the seam lies flat after cooling and that support removal does not gouge the air path. |
| Bell-mouth inlet | Start with the flat throat mounting face down and mouth up. The outer lip approaches a horizontal overhang; test a section and use accessible support on the exterior if the profile needs it. Do not fill the curved internal air surface with inaccessible support. |
| Radial straightener | Put a circular end face down, with the airflow axis vertical. Confirm the ring, hub and every vane grow continuously together. Reject missing lines, loose strings or a detached vane. |
| Fixed inner and rear guards | Put the flat grille face down. Rear mounting posts then grow away from the bed. Check rib adhesion, open slots and post strength; a slicer preview is not a finger-access test. |
| Front grille and magnet keeper rims | Print broad faces flat. Confirm the magnet skins and thin keepers are continuous, with no pinholes or lifted corners. Keep mating surfaces flat enough to prevent rattle. |
| Boost panels | Trial the broad outside face down, retaining a smooth air face. Horizontal hinge bores may need local support and finishing. Print a short section first; use an alternate edge orientation only after checking warping and layer strength at the keyed hinge end. |
| Yoke, rod, separate cranks and spacers | Prefer a broad face on the bed with pivot-hole axes vertical where the shape permits. Keep elephant foot out of sliding slots and key sockets. A separate crank avoids making the panel's print orientation serve the entire linkage. |
| Base shell | Start roof down with the service opening upward. Check the USB opening, encoder shroud, light wells and screw bosses for accessible support. Verify the flat roof and head supports remain true. |
| Service tray | Start its flat underside toward the bed, with board supports upward. Check underside nut pockets, the USB fascia and light recesses in layer preview before choosing support. |
| Diffusers | Print flat with consistent layer direction and a repeatable surface finish. Compare transmitted light before selecting thickness; opaque paint or foil must not contact electronics. |
| Screen cradle and front bezel | Put each broad face on the bed. Inspect cable cutout, PCB posts and screw bores in the slicer. Use clear 1 mm acrylic for the window; an FDM diffuser would obscure the screen. |
| TPU pieces | Print on a broad flat face using the material's supported profile. Keep each pad/foot separately replaceable. Confirm fill pattern does not leave unsupported compression surfaces. |

Remove burrs and strings, deburr shaft ends and clear designed passages. Hand-ream a selected bore only as needed; do not enlarge all bearing holes blindly. Lightly smooth inlet and nozzle surfaces without changing the measured throat or removing thin vane/panel walls. Clean all debris before installing the fan. Keep adhesive, lubricant and heat-set tooling away from rotor bearings, electronics, pressure bores and sliding guide surfaces.

Install heat-set inserts before purchased electronics and TPU. Use a depth stop and a matching screw to check alignment after cooling. Screws must not bottom in blind inserts. Metal compression sleeves set rigid fan alignment; washers and the selected TPU compression provide compliance without bending the fan frame. Record the final sleeve length and stack instead of relying on a reference cylinder as a cut drawing.

## Mechanical assembly sequence

This is the intended sequence for the current split head and separate keyed cranks. Complete the source-matched insertion checks and tool-access review before a full print. Checks at sampled positions establish nominal rigid clearance only; they do not establish hand access, wiring clearance or tolerance extremes.

1. Inspect all printed parts and complete the coupon decisions. Dry-fit head halves, rear inlet and base without purchased loads. Inspect the integral outlet surfaces and remove every loose particle. Install the required inserts and captive nuts while their pockets are accessible.
2. Prepare the right head half on a support fixture with its split face accessible. Feed the yoke into the outboard guides before connecting either crank. Place the crank-retaining spacers and separate keyed cranks in their outboard locations. The generated insertion study approaches the upper crank from above and the lower crank from below; keep those paths clear.
3. Slide the upper and lower panels into the open split from the left, engaging each double-flat hinge end with its matching crank socket. Keep both panels fully open and parallel. After closing the left shell in step 5, insert the metal hinge shafts from the left through the bearings, spacers and panel bores. Do not force a misaligned key or use a screw to pull the panel into position.
4. Fit the radial straightener, TPU axial shim and fixed inner guard into their respective seats before closing the head. The straightener ring is located between its rear stop and shim/guard stack; verify gentle axial capture without deforming the guard. For an approved comparison run without vanes, maintain guard location and capture with a suitable ring/spacer; do not leave a loose stack.
5. Close the left head half over the aligned assembly. Start all seam screws before tightening evenly. Fit the specified shaft collars outside the bearings, set the measured axial clearance and secure their set screws. Fit crank clamp fasteners with the shaft present, using only enough preload to remove backlash. Check free panel motion again.
6. Fit smooth sleeve/washer stacks through the crank-yoke and rod joints. Tighten onto the metal sleeves so the printed eyes and slots remain free. Fit the removable servo bracket loosely, then the actual servo. Keep its horn disconnected until electrical centring has established a safe pulse. Retain access to the supplied horn's centre screw, bracket screws, collar set screws and crank clamps.
7. Install the fan with airflow toward +Y, its purchased pads and final TPU/metal limiter stack. Route the original cable outside the rotor aperture. Tighten corner mounts evenly to their established stop; verify the rotor remains clear of rigid and soft parts. Fit the bell-mouth and rear guard with the specified rear screw stack. Guard support loads must not distort the inlet.
8. Assemble the four magnet pairs on the bench and mark the attracting faces before adhesive is introduced. Load each head and grille pocket from its designed accessible side, keep magnets seated, then fit the screw-retained rims. The adhesive removes rattle; the retainers prevent a released magnet entering the airflow. Confirm all four pairs attract in the final orientation and the grille can be intentionally peeled away without pulling a keeper off.
9. Fit and adjust the grille-present switch only after its actual mount and contact travel are resolved. Use COM/NO as specified in the wiring document. Verify the removable grille closes the switch reliably without forcing its lever to its hard end. Keep the fixed guard fitted independently. Finish the linkage cover and check its full motion clearance before powered operation.
10. Attach the head to the base using its four support locations while the underside is open for screw access. Confirm no fastener intrudes into the air path and that the head is square to the base. Fit the horizontal encoder in its bushing-supported mount, then the wheel. Verify the exposed rim rolls up/down, pressing acts along the horizontal shaft, and the base does not slide or tip during a press.

Do not improvise an enclosure closure around an unresolved insertion trap. Change the relevant retainer or split and repeat the path check. The head halves must continue to carry the final nozzle; a detachable outlet module is not the remedy for an assembly-order problem.

## Electronics, lighting and service closure

Complete the independent electrical checks in [electronics-assembly.md](electronics-assembly.md) before installing boards in the base. The 90 × 65 × 22 mm carrier reserve is an allowance, not a fabricated board. Its final connectors, mounting holes, component heights and tool access must agree with the carrier design before release. The Adafruit 1782 temperature-board model matches the manufacturer’s current non-STEMMA revision; the 2023 change was silkscreen only. Compare the approximate encoder and servo envelopes with the supplied parts.

Install the tray-mounted Pico, regulator and PD modules with their insulating supports and specified fasteners. Use the current generated fastener table; confirm screws and nuts do not touch traces or underside components. Direct-solder the pressure sensor’s four 2 mm-pitch pins to its dedicated daughterboard. Use the two M2 x 20 housing fasteners, two M2 x 6 daughterboard fasteners and four M2 x 14 temperature-board fasteners with the captive nuts in the tray. The daughterboard is an outline and hole pattern; it still needs routing and fabrication data. Support the USB board at its mounting holes; do not transfer plug insertion loads through soldered signal wires. The USB fascia travels with the service tray so the connector can withdraw through the shell's bottom opening.

Fit four RX-M2x4 bezel inserts in the front shell's 3.2 mm pilots and four RX-M3x5.7 cradle inserts in its 4.0 mm pilots before installing electronics. Fit the Adafruit 4311 board to the cradle's two actual 2.5 mm PCB holes using two M2 × 12 screws and captive M2 nuts. Feed the header loom through the left cutout. Move the cradle upward through the open base, then forward 2 mm into position; secure it with four M3 × 8 screws from the rear. Its active face points toward +Y. Check the current EYESPI board's rear connector against the older manufacturer STEP before fastening.

Cut a clear acrylic window 45 × 34.4 × 1 mm, deburr it, and retain its perimeter in the bezel with 0.05 mm 3M 467MP transfer film. The recess provides 0.2 mm edge clearance and the nominal LCD-to-window gap is 0.76 mm. Secure the bezel with four M2 × 6 screws; do not tighten against the LCD. Test the visible image and all service patterns before closing the tray. The moved front tray screw is at X=75, Y=133 mm so it clears the screen service path.

Mount the eight-pixel ambient stick facing the desk, observing DIN/DOUT direction, and install its diffuser and screw-retained keeper. Verify no bare copper or solder joint touches a screw, insert or optical part. The main speed and power/status light bars are replaced by the screen's top section; their old front diffusers and LED boards are not parts of this revision.

Label every harness at both ends using the connector names in [wiring.md](../hardware/wiring.md). Similar keyed housings still need labels. Route power with its return; keep sensitive analog and pressure wiring away from regulator switching nodes and servo current loops. Secure looms to the final cable-management features, leaving sufficient slack for the defined tray service position and connector removal. Keep the pressure tubing outside hinge, yoke and fan sweeps, without tight bends or tension on sensor nipples. The positive tap must be flush and clear; the ambient reference must be sheltered from the inlet and outlet jet.

With power disconnected, move the panels through the entire range while observing all wires, tubes and cover clearances. Withdraw the service tray along its defined path and check that no plug, nut, USB overmould or loom becomes trapped. Support the tray during service rather than letting it hang by its harness. Connect the servo horn only at the measured open position, then follow the complete five-point calibration procedure. Close the base and fit its TPU feet only after electrical, input, light and guarded mechanism checks pass. Repeat the enclosed thermal and power tests; an open-bench pass does not qualify the closed enclosure.

## Cleaning and replaceability

Unplug USB-C and wait for the rotor to stop before removing the magnetic front grille. The switch cannot stop rotor coast instantly. Wipe or brush printed surfaces without forcing debris into bearings or pressure taps. Do not soak the installed motor, magnets or electronics. Removing the cosmetic grille does not authorize operating with the fixed inner guard removed.

For screen service, remove the front bezel/window, unplug J6, remove the electronics tray, then undo the four rear cradle screws. Withdraw the screen and cradle 2 mm rearward and lower them through the open bottom. The current nominal rigid geometry passes 174 sampled path checks with no intersections. That result excludes hands, tools and loose wiring, so qualify those clearances on the fascia coupon before a full enclosure print.

The tray provides access to electronics, internal Pico service USB and the calibration jumper. The linkage cover provides access to the servo, horn and pivots. Shaft collars permit later panel removal using the reverse of the verified insertion sequence. Replace TPU pieces that develop permanent set or cracks, and recheck alignment after retightening. Any replacement servo, changed linkage fit, sensor circuit revision or altered airflow limit requires recalibration and the affected validation tests.

Before calling a print set released, attach its CAD/source revision, generated manifests, zero-unintended-interference evidence, insertion/tool-access review, slicer profiles, final hardware quantities and coupon results. Physical qualification records belong in the companion validation log; none are inferred from the existence of an STL.

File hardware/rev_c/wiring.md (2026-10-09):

# Rev C wiring and pin assignments — 8 October2026

The source of these tables is the checked [native circuit population](../pcb/rev_c/circuit-population.json). Use the [complete10-sheet schematic](../pcb/rev_c/windflow-rev-c-schematic.pdf) for component pins and protection. This describes the electrical connections; the main PCB and complete installed loom are still under development. Rev B25kHz fan control and its keyed Pico cable are incompatible with Rev C.

## Power path

USB-C15V3A contract → Adafruit5807 → J1/F1 → reverse-blocking CSD19537Q3/TPS26630 EF1 → protected15V bus. The ESC path adds F2 and default-off EF2, then J20 → suppliedXT30 → A50S. The three motor phases use the suppliedMR30 pair. Two D24V22F5 modules supply independent5V logic and servo rails. The servo and ambient rails have their own controlled switches. All returns join system ground. No load current runs through Pico GPIO or the Pico ribbon. The ESC BEC and3.3V outputs are insulated and unconnected.

Use22AWG for the protected power/5V branches and26AWG for signals. Keep phase leads apart from UART, I2C and ADC wiring. Use the included ESC loom for its20-cavity interface; only vendor-labelledGND,TX,RX are connected. Cavity numbers are not inferred from an unnumbered drawing. UART TX/RX cross, with a nearby ground return and a maximum150mm signal route. C38/C39/D3/R80 are at the ESC end behind the gate; C30/R56 are at the screen end.

## Removable cable connectors

Pin numbers below are the PCB footprint numbers. Determine the actual latch/pin1 view from the manufacturer drawing before crimping; do not copy a mirror image seen from the wire entry. All unused contacts remain unconnected.

| Board connector | Selected board part | Pin-to-net assignment |
|---|---|---|
| J1 | JST B2B-XH-A(LF)(SN) | 1 PD_RAW, 2 GND |
| J18 | Molex 43045-0412 | 1 GND, 2 BUS_PROTECTED, 3 REG5_LOGIC, 4 NC |
| J19 | Molex 43045-0812 | 1 GND, 2 BUS_PROTECTED, 3 REG5_SERVO, 4 PG_SERVO, 5 NC, 6 NC, 7 NC, 8 NC |
| J4 | Samtec TSW-103-07-G-S | 1 GND, 2 SERVO5_SWITCHED, 3 SERVO_SIGNAL |
| J5 | Samtec TSW-101-07-G-S | 1 SERVO_FEEDBACK_RAW |
| J7 | JST B3B-XH-A(LF)(SN) | 1 GND, 2 AMBIENT5_SWITCHED, 3 AMBIENT_DATA |
| J2 | JST B3B-XH-A(LF)(SN) | 1 GND, 2 I2C_SDA, 3 I2C_SCL |
| J8 | JST B4B-XH-A(LF)(SN) | 1 GND, 2 ENC_A, 3 ENC_B, 4 ENC_PUSH |
| J9 | JST B4B-XH-A(LF)(SN) | 1 GND, 2 +3V3, 3 I2C_SDA, 4 I2C_SCL |
| J10 | JST B4B-XH-A(LF)(SN) | 1 GND, 2 +3V3, 3 I2C_SDA, 4 I2C_SCL |
| J11 | JST B4B-XH-A(LF)(SN) | 1 GND, 2 +3V3, 3 I2C_SDA, 4 I2C_SCL |
| J12 | JST B2B-XH-A(LF)(SN) | 1 GND, 2 GUARD_CONTACT_5V |
| J14 | Samtec TSW-102-07-G-S | 1 GND, 2 SERVICE_JUMPER |
| J6 | JST B8B-XH-A(LF)(SN) | 1 REG5_LOGIC, 2 GND, 3 TFT_MOSI, 4 TFT_SCK, 5 TFT_CS, 6 TFT_DC, 7 TFT_RST, 8 TFT_BL |
| J20 | Molex 43045-0212 | 1 GND, 2 ESC_15V |
| J22 | JST B3B-XH-A(LF)(SN) | 1 GND, 2 UART_TO_ESC_RX, 3 UART_FROM_ESC_TX |
| J21 (DNP) | JST B3B-XH-A(LF)(SN) | 1 GND, 2 +3V3, 3 OPTICAL_RPM |

J8 mates the encoder daughterboard J1, pin1GND/pin2A/pin3B/pin4PUSH. J9/J10 go to the MCP9808 breakouts at0x18 and0x19; J11 goes to the SDP810 daughterboard at0x25. J2 carries GND/SDA/SCL to the already powered HUSB238 board. J12 goes to Omron COM/NO; insulate NC. Its raw contact is5V, translated before GP15. The FEETECH supplied servo plug goes to J4; the separate feedback wire goes to J5. Confirm real lead colors/positions against the supplied servo.

## Pico physical pins and ribbon mapping

J15/J16 are keyed2×10 headers with all20 contacts. Connector pin n maps to Pico physical n for J15 and n+20 for J16. These mappings require a purpose-built Pico-side transition and strain relief; they are not a direct mechanical plug into the Pico1×20 rows. That transition is unfinished design work. Label the two looms separately and continuity-test all40 contacts before applying power.

| Pico physical pin | Pico function | Carrier connector | Net / use |
|---:|---|---|---|
| 1 | GP0 | J15.1 | ENC_A — Encoder A |
| 2 | GP1 | J15.2 | ENC_B — Encoder B |
| 3 | GND | J15.3 | GND |
| 4 | GP2 | J15.4 | ENC_PUSH — Encoder push |
| 5 | GP3 | J15.5 | OPTICAL_RPM — Optional optical RPM; unpopulated/untrusted |
| 6 | GP4 | J15.6 | I2C_SDA — I2C SDA |
| 7 | GP5 | J15.7 | I2C_SCL — I2C SCL |
| 8 | GND | J15.8 | GND |
| 9 | GP6 | J15.9 | ESC_POWER_REQUEST — ESC power request to hardwired guard AND |
| 10 | GP7 | J15.10 | TFT_RST_GPIO — Screen reset |
| 11 | GP8 | J15.11 | SERVO_PWM_GPIO — Servo50Hz PWM |
| 12 | GP9 | J15.12 | EN_SERVO — Servo supply enable |
| 13 | GND | J15.13 | GND |
| 14 | GP10 | J15.14 | TFT_DC_GPIO — Screen DC |
| 15 | GP11 | J15.15 | AMBIENT_DATA_GPIO — Ambient addressable data |
| 16 | GP12 | J15.16 | UART_TX_GPIO — UART0TX to ESC RX via BUF5 |
| 17 | GP13 | J15.17 | UART_RX_GPIO — UART0RX from ESC TX via BUF5 |
| 18 | GND | J15.18 | GND |
| 19 | GP14 | J15.19 | EN_AMBIENT — Ambient supply enable |
| 20 | GP15 | J15.20 | GUARD_LOGIC_3V3 — Grille contact; LOW means present |
| 21 | GP16 | J16.1 | TFT_BL_GPIO — Screen backlight |
| 22 | GP17 | J16.2 | SERVICE_JUMPER — Service shunt |
| 23 | GND | J16.3 | GND |
| 24 | GP18 | J16.4 | TFT_SCK_GPIO — Screen SPI SCK |
| 25 | GP19 | J16.5 | TFT_MOSI_GPIO — Screen SPI MOSI |
| 26 | GP20 | J16.6 | TFT_CS_GPIO — Screen CS |
| 27 | GP21 | J16.7 | PG_SERVO — Servo branch PGOOD |
| 28 | GND | J16.8 | GND |
| 29 | GP22 | J16.9 | PG_ESC — ESC branch PGOOD |
| 30 | RUN | J16.10 | NC |
| 31 | GP26/ADC0 | J16.11 | ADC_BUS — Protected bus ADC; divider11.1 |
| 32 | GP27/ADC1 | J16.12 | ADC_SERVO_FEEDBACK — Servo feedback ADC; divider2.1 |
| 33 | AGND | J16.13 | GND |
| 34 | GP28/ADC2 | J16.14 | ADC_LOGIC — Logic5V ADC; divider2.1 |
| 35 | ADC_VREF | J16.15 | NC |
| 36 | 3V3_OUT | J16.16 | +3V3 |
| 37 | 3V3_EN | J16.17 | NC |
| 38 | GND | J16.18 | GND |
| 39 | VSYS | J16.19 | PICO_VSYS |
| 40 | VBUS | J16.20 | NC |

RUN,ADC_VREF,3V3_EN andVBUS stay unconnected at this carrier. Pico VSYS is diode-fed from the logic regulator; 3V3_OUT powers3.3V buffers/sensors. Powered USB programming must be checked for backfeed through the finished circuit.

## Commissioning sequence

1. Leave the motor/impeller disconnected. Check every cable contact against these tables, including no shorts to adjacent pins and all NC insulation.
2. Verify unsupported5V USB leaves motor permission off. Confirm the selected source negotiates15V3A and the measured bus is within limits.
3. Check protected bus, both5V rails, Pico3V3, ADC scale and I2C addresses before enabling loads.
4. Remove/reseat the grille: verify the contact, GP15 and EF2SHDN independently. Reset/boot must leave the motor branch off.
5. Check servo feedback/open position and its bounded jam cutoff with rotor absent. Check display, wheel/countdown, night mode and ambient dimming.
6. Verify UART levels, both power sequences, stale telemetry and ESC timeout. Follow the guarded motor/impeller qualification procedure before any motion build.

Cable lengths, clips, bend envelopes, shield/return routing and populated-tray service slack need source-matched physical CAD integration. Nominal unplugged screen removal is not a connected-loom removal qualification.

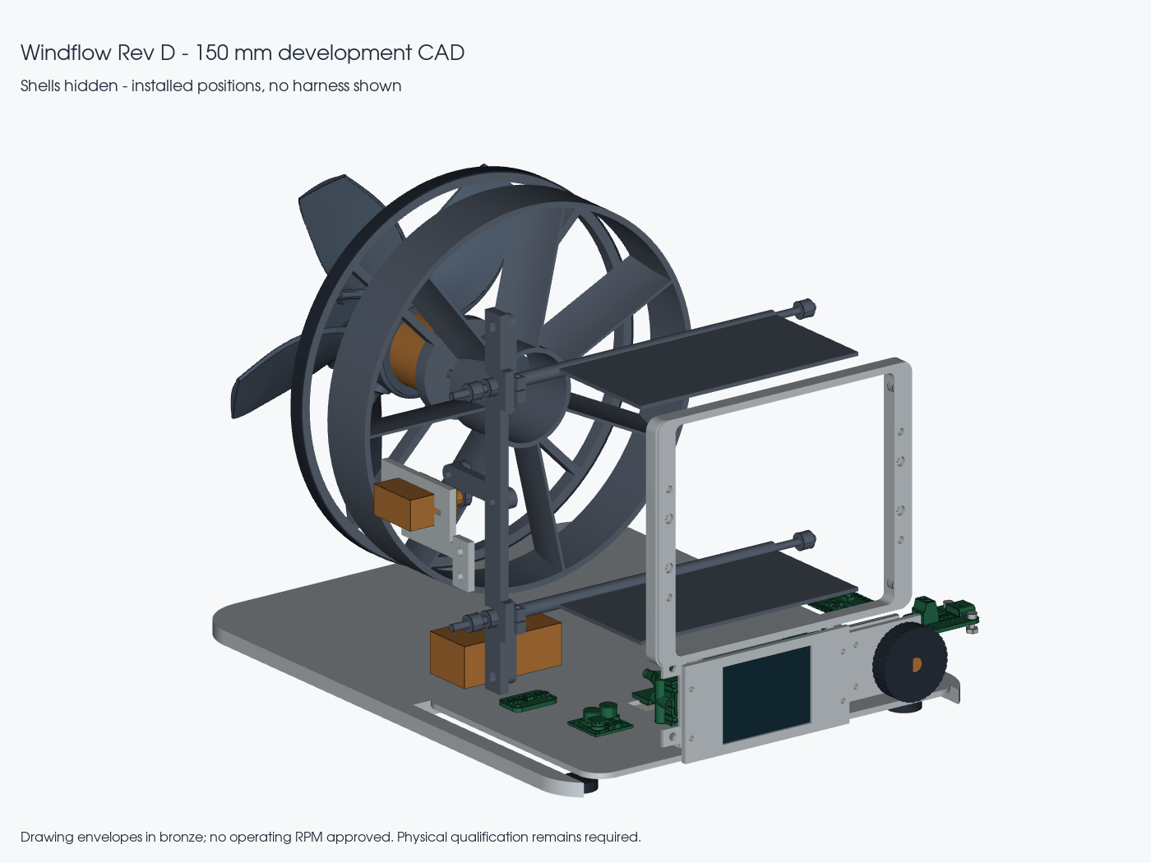
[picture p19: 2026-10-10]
cad/evidence/rev-d-installed-internal-2026-10-10.png

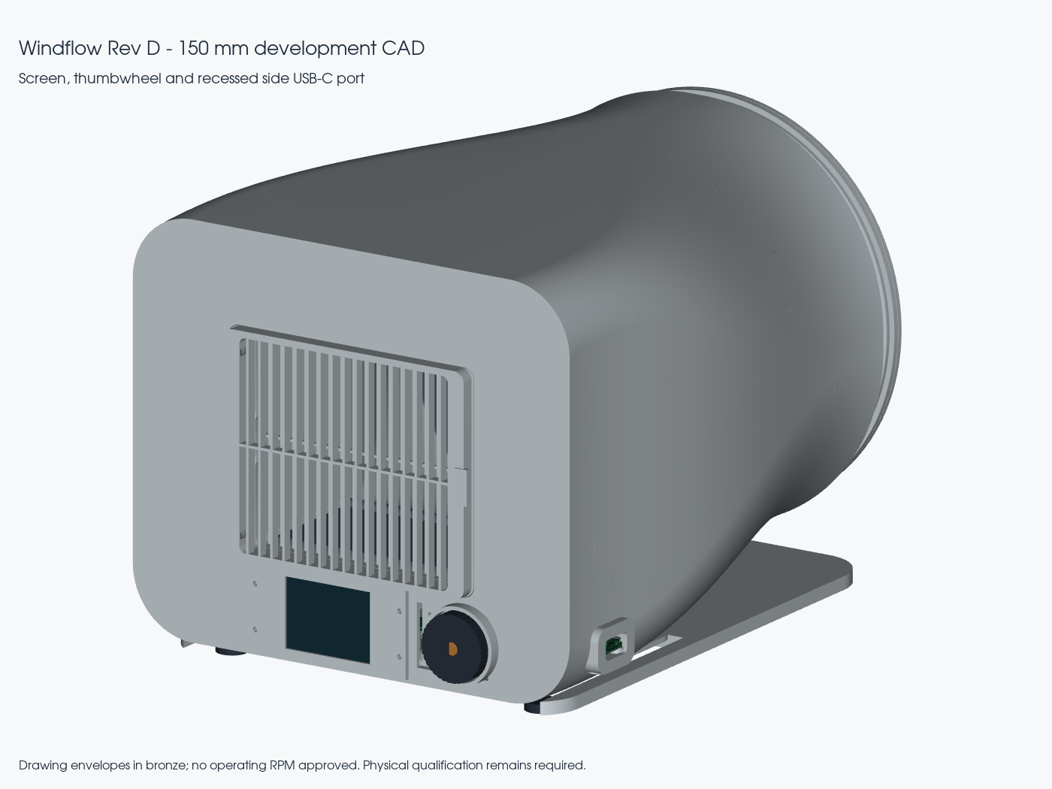
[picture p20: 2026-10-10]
cad/evidence/rev-d-installed-controls-and-power-2026-10-10.png

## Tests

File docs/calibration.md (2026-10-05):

# Calibration and commissioning

Follow this with the final wiring and mechanical assembly drawings. The default firmware is uncommissioned and intentionally does not start loads. Calibration values are specific to the actual fan, servo, linkage, divider circuit, pressure taps and sensors. Keep a written measurement log with component serial/lot identifiers, panel angles, pulse widths, ADC values, RPM, pressure, rail voltages and temperatures. The software records evidence of stable measurements; it cannot determine whether an angle was physically measured correctly.

## Before applying power

Check regulator outputs and connector polarity with the loads disconnected. Confirm that PD requests **15 V / 2 A**, that no 15 V net reaches the Pico or fan directly, and that load-switch enables default low. Use the revised ADC-isolation circuit and switched-rail servo buffer specified in the wiring document. Check rail rise times with the selected 100 nF slew capacitors and bulk capacitors. The firmware waits 50 ms before sending ambient LED data. Confirm the screen CS/reset buffer and its third channel for BL are fitted: R55=330 ohm output series, R56=1k at the display to GND, R59=100k on the GP16-side buffer input to GND. CS/RST have onboard pullups to 5 V VIN and must not connect directly to Pico GPIO. Measure BL HIGH/LOW and verify complete visible darkness at night brightness zero and during powered reset, cold connection, slow rail rise/fall and watchdog restart. The calculated ideal LOW is about 0.08 V; transistor identity/temperature and buffer ramp behavior still require measurement.

Fit both temperature sensors at their intended locations; confirm addresses 0x18/0x19. Fit SDP810-125Pa at 0x25 with pressure tubing clear of moving parts. Verify the intended pressure polarity using a small known pressure source within sensor range. Fit the guard switch and guards. Keep the servo horn/linkage **disconnected for its first electrical centering operation**: an uncommissioned servo starts service jogging from 1500 us, which is not a known safe assembled-linkage position.

Initially inspect the mechanism by hand with power disconnected. Establish the fully open position, useful closure limit, hard stops, clearances and horn indexing without forcing the servo. Reconnect the linkage only when its pulse range and indexing are known. Hardware protection, a current-limited bench supply for initial isolated rail tests, and an accessible power disconnect are needed for commissioning; software feedback is not a substitute for these checks.

## Enter service mode

1. With power disconnected, fit the recessed service jumper from GP17 to ground.
2. Hold the encoder push switch while connecting the final PD supply. Continue holding for **4 seconds**. The jumper and button must already be present during the first 150 ms of startup.
3. Open the Pico's USB CDC serial port at 115200 baud. Use a verified USB data path described in the wiring document; avoid connecting two USB hosts. A data-only host connection does not satisfy the PD power requirement for actuator tests.
4. Send `status` and `help`. `state=6` means Service. If there is a latched fault, inspect the indicated condition before `ack`; acknowledgment returns to normal boot with the fan off, so re-enter service by the deliberate boot procedure if needed.

Remove the jumper after commissioning. Holding the encoder during ordinary operation only toggles night mode. A watchdog-reset fault cannot be bypassed by the service boot gesture.

## Commands

Commands are case sensitive, space separated and terminated with a newline. `status`, `help` and `ack` are available outside service. Tests expire automatically; the console must not be used to repeatedly force an obstructed mechanism.

| Command | Meaning |
|---|---|
| `status` | State/fault number, setting, PWM, closure, RPM, pressure, temperatures, measured rails, commanded pulse, ADC feedback, sensor/guard/PD validity, commissioned/filesystem flags |
| `evidence` | Five-point capture bitmask and pressure-zero/minimum-RPM/maximum-RPM evidence flags; complete captures are `0x1f` |
| `set KEY VALUE` | Change a validated setting; geometry, fan, sensor, safety, direction and LED-count changes clear commissioning/evidence. The four brightness/night fields retain calibration. |
| `jog -10` through `jog 10` | Adjust servo command by at most 10 us; power it for 0.8 seconds; `jog 0` briefly holds the present command |
| `capture 0` through `capture 4` | Record commanded pulse and stable ADC feedback for the physically measured panel angle |
| `fan 0` | Stop fan and servo test power immediately on the next control tick |
| `fan 20` / `fan 100` | Test the stated percentage duty for up to 10 seconds, bounded by configured maximum PWM; requires captured open position and current feedback near it |
| `measure fan-min` | Accept stable tach observations at the configured minimum duty |
| `measure fan-max` | Accept stable tach observations at configured maximum duty and record measured `rpmAtMax` |
| `zero` | Record mean pressure after at least 1 second of stable zero-flow readings |
| `led INDEX R G B` | Test one downward ambient pixel for 2 seconds: indices 0–7 only, RGB values 0–80; the screen does not use pixel indices |
| `screen 1` through `screen 5` | Service-only 2 second screen pattern: 1 red, 2 green, 3 blue, 4 white, 5 checker grid; faults override the pattern |
| `format ERASE` | Explicitly format the settings filesystem with both actuators off; needed on a new unformatted board, never a routine troubleshooting step |
| `commit MEASURED` | Validate/save after complete fresh evidence, or save an already commissioned profile after cosmetic-only changes; healthy sensor/power and loads-off checks still apply |
| `exit` | Leave service and return to startup qualification; uncommitted settings remain uncommissioned |

Fault codes: 0 none, 1 power, 2 temperature sensor, 3 overtemperature, 4 stall/abnormal RPM, 5 servo, 6 pressure, 7 guard, 8 watchdog. State codes: 0 waiting power, 1 uncommissioned, 2 homing, 3 ramp up, 4 ramp down, 5 live, 6 service, 7 fault.

## Configure before collecting evidence

Set any needed fields first. Available keys are `boostThreshold`, `minAreaRatio`, `minPwm`, `maxPwm`, `rpmAtMax`, `pressureSoft`, `pressureHard`, `warnC`, `tripC`, `busScale`, `logicScale`, `encoderReverse`, `ambientCount`, `mainBrightness`, `ambientBrightness`, `nightMain`, and `nightAmbient`. Fractions use 0–1; booleans use 0 or 1. `mainBrightness` now sets the screen backlight (default 60, allowed 0–80), `nightMain` sets night backlight (default 0, allowed 0–4), and `ambientBrightness`/`nightAmbient` set the downward strip. `mainCount` is reserved at 16 and no longer a service key. `ambientCount` remains 1–8. Brightness can be adjusted before or after commissioning using the cosmetic-only save procedure below.

Default voltage scales are **11.1 bus** and **2.1 logic**, including the ADC-side 1 megohm pulldowns. Compare `status` rail readings with a calibrated meter. A correction is `newScale = oldScale * meterVoltage / displayedVoltage`; validate it at more than one voltage within the supported operating range. Bus scale is restricted to 10–12.2; logic scale to 1.9–2.3. Values outside those ranges indicate a circuit or measurement problem rather than a value to force into the firmware.

The internal stored-setting boundary `boostThreshold` initially remains 0.75, allowed 0.60–0.90. It is not a visible automatic boost crossover: normal maximum stays fully open, followed by the required 24-detent /360 degree entry turn. A further 24 detents controls progressive boost. Entry/re-entry travel uses the constants in Config.h, not the servo calibration table. Initial minimum area is 0.75, allowed 0.75–0.95. Use a larger area ratio to reduce constriction; never tune below 0.75 using the service console. Minimum PWM is allowed 0.20–0.40 and maximum 0.60–1.00. Default thermal warning/trip are 55/65 C; warning must be 40–58 C and trip at least 5 C above warning, no higher than 70 C. Pressure soft/hard start at 18/24 Pa, require at least 3 Pa separation, and cannot exceed 26 Pa hard.

The four cosmetic fields `mainBrightness`, `ambientBrightness`, `nightMain` and `nightAmbient` keep existing commissioning and session evidence after validation. In service, stop both actuators, adjust these fields, then use `commit MEASURED` to save the retained commissioned profile; the same guard, rail, sensor and temperature checks still apply. A previously uncommissioned profile cannot become commissioned through a brightness change. Every other `set` clears commissioning and session evidence. If a measurement leads to a changed noncosmetic setting, repeat the evidence collection after the last change. A schema change, different servo/divider/linkage, altered area limit, or changed fan requires recalibration.

## Measure the five servo points

The table corresponds to **equal fractions of maximum panel angle**, not equal servo angles, outlet area increments or pulse increments. For the default 94 mm outlet height, 55 mm panels and minimum area ratio 0.75, measure:

| Capture index | Panel angle inward from open |
|---|---:|
| 0 | 0 degrees |
| 1 | 3.0839 degrees |
| 2 | 6.1678 degrees |
| 3 | 9.2517 degrees |
| 4 | 12.3355 degrees |

If `minAreaRatio` changes, calculate `maximumAngle = asin(94*(1-minAreaRatio)/110)` in degrees and use 0%, 25%, 50%, 75%, 100% of that angle. Both opposing panels must reach the same angle without racking. Make a gauge/test jig and measure both sides. Do not use the manufacturer's servo travel range as a proxy for panel angle.

Approach each point in small jogs with the fan off. Establish that the servo is not pulling against a hard stop. At the measured position, send `jog 0`, allow about **0.3–0.5 seconds** for steady feedback, then issue the relevant `capture` before the 0.8-second test timeout. Capture requires at least 250 ms of stable command/feedback, ADC spread at most 12 counts and healthy sensors/PG. Repeat the hold/capture if necessary; never automate continuous retries into a stop.

All five pulse values and all five ADC values must each be strictly monotonic; either increasing or decreasing direction is accepted independently. Pulses must be 900–2100 us with an overall span 80–800 us; feedback must be 50–3200 counts with at least 120 counts total span. A feedback value near a supply rail, abrupt jumps, a reversed point or excessive friction needs correction. Record pulse/ADC values from `status` with the measured panel angle in the test log.

## Zero pressure and measure fan operation

Stop both test loads with `fan 0`; let the rotor coast completely to rest. With ports at the intended zero differential, wait at least one second and send `zero`. Readings must be within +/-2 Pa, span no more than 0.5 Pa, and tach must be below 60 RPM. This captures the mean, rather than one instantaneous sample. If a draft or plumbing error prevents stable zero, fix that first.

**Secure the panels fully open for fan-only tests.** Service fan testing switches the servo supply off, so the mechanism must not depend on powered holding torque during this test. Keep guards fitted and use an open-position fixture outside the airflow path. Briefly use `jog 0` at the captured open command, then issue the fan test while feedback still confirms the open position. Do not bypass the guard input to reach the mechanism with the rotor running.

At default settings, run `fan 20`, wait **5–7 seconds**, then `measure fan-min` before the 10-second timeout. The measured RPM must be at least 250 and stable: peak-to-peak spread no greater than the larger of 80 RPM and 20% of mean. The first two seconds are excluded from the measurement. Repeat cold/warm starts on the bench; a single running sample does not prove reliable starting. If the fan stalls or is unstable, increase `minPwm` within range and repeat the calibration evidence after that `set`.

Return to fully open and test `fan 100` (or the configured maximum percentage); after 5–7 seconds send `measure fan-max`. It requires the same stability checks and an average in 1000–2100 RPM. That measured average becomes `rpmAtMax`. Then `fan 0`. Compare tach against an independent tachometer and confirm the selected fan really outputs two pulses per revolution.

A service test exceeding the soft pressure limit or thermal warning stops test loads. All normal hard safety inputs remain effective. Service does not provide an unrestricted high-pressure sweep. Subsequent live boost testing must use an assembled guarded mechanism with calibrated feedback and pressure protection active.

## Screen, ambient lighting, direction, sensors and commit

Verify wheel direction, detents and press feel mechanically; set `encoderReverse` before the final evidence run if needed. At 24 detents per revolution, confirm the screen's relative angle advances 15 degrees per detent and wraps at 360 degrees. The encoder is incremental, so the dial is relative to boot rather than a measured absolute shaft position. Verify zero-to-normal-maximum takes exactly 24 detents. Below maximum, the total remaining angle includes those normal detents plus 360 degrees; it must show 720 degrees at zero, 540 at stored 400, and exactly 360 at maximum before entry starts. Check the display in landscape 320 x240 orientation and read it from the expected desk position; retain the top 64 rows for speed/boost, USB/status/fault and night indications. Use `screen 1` through `screen 5` to check color order, white uniformity, orientation and pixel grid. Check blue normal and purple boost with their text labels, adequate contrast, backlight dimming, night mode and readable essential faults. Service/fault displays force at least 36/255 backlight and thermal warning at least 16/255; these essential overrides must work even with `nightMain=0`. Verify there is no bright flash during reset or reconnect. Install the four RX-M2x4 bezel inserts in the Ø3.2 mm through pilots using a coupon first; use M2x6 screws, and confirm they neither bottom nor load the glass. The nominal 1.4 mm boss wall and 4.5 mm axial length are CAD dimensions, not a pullout-strength result.

Test each ambient pixel at low intensity, for example `led 0 8 0 0`, and repeat green/blue to establish color order and addressing. Confirm the 8-pixel count and downward diffuser brightness. The former 16 main pixels and discrete RGB status LED are removed. Check both temperature channels against a reference at room temperature and a controlled elevated temperature; do not deliberately overheat a regulator. Sensor positions must represent the protected components without nuisance trips from unrelated hot air.

With both actuators off, send `evidence`. It must report captures `0x1f`, zero `1`, fanMin `1`, fanMax `1`. Send `commit MEASURED` only after the recorded physical angles and measurements are correct. Commit also requires valid settings, fitted guard, both regulator PGs, good sensors, a bus of 14.5–16 V, logic rail 4.65–5.35 V and both temperatures at least 5 C below warning. If the new board has no filesystem, use `format ERASE` before the evidence sequence; formatting clears evidence.

Successful commit means the record was written, read back and verified. It does not prove airflow, torque or physical safety. Send `exit`, remove the service jumper with power disconnected and verify normal startup. With the default saved setting, this will run the startup full-power ramp before returning to normal control. Clear the bench and fit guards first.

## Physical acceptance and tuning log

Check normal mode at multiple duties, then increase boost gradually. Log outlet velocity profiles, useful flow/throw, pressure, RPM, noise at a fixed distance, servo current, regulator/air temperatures and any vibration. Evaluate normal power 25%, 50%, 75%, 100% with the nozzle open, then complete the entry turn and evaluate boost 0%, 25%, 50%, 75%, 100%; reverse to zero boost to detect hysteresis. Confirm the final entry detent leaves the nozzle open and the next detent begins progressive closure. A smaller outlet does not guarantee a faster useful jet: choose a less-constricted endpoint if measured velocity, noise or stability worsens.

Verify safe reactions using controlled tests: remove the guard with power managed; interrupt tach or position feedback electrically; apply simulated temperature inputs in a dedicated test build/fixture; disconnect the pressure sensor; and reduce input voltage with a suitable bench fixture. Do not put fingers or tools into a spinning fan. Confirm loss of servo position stops the fan, rather than assuming the panels can open after a servo power failure.

Test saved-setting persistence after more than 8 seconds of inactivity and 60 seconds since the preceding save, then disconnect/reconnect power. Repeat controlled power cuts around writes and check fallback to a valid older record. Confirm short press, 1.2-second night press, saved off/zero startup, night restart, startup cancellation, fault acknowledgment, service timeout and calibration-entry resistance to accidental gestures. Exercise the new interaction: 23 upward entry detents leave 15 degrees remaining and no constriction; the 24th enables boost control without closure; the 25th begins boost. Reverse partway through entry, reverse all boost travel to zero, and confirm another full 360 degrees is required. Turn off, reboot from a saved boost command, interrupt entry with a fault and use service/startup controls: none may bypass or queue the deliberate entry turn. Scope/check that screen refresh does not delay the 10 ms safety-control tick. Flash-write and input responsiveness tests must use the actual board, not only the host simulation.

Record pass/fail and measurements for every hardware check. Until these tests are completed, the pressure/thermal thresholds, minimum PWM, servo LUT, maximum closure, screen readability/brightness/current, vibration mounts, grille retention and airflow claims remain prototype tuning values.

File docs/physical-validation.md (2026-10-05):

# Physical validation and tuning

Rev B has analytical geometry, manufacturer references and software tests. No airflow, acoustic, thermal, force, endurance or physical assembly result is claimed here. This plan defines the measurements needed to turn the development design into a tested prototype. Record a pass, failure or explicit outstanding dependency for every test; do not label an unbuilt mechanism or unexecuted test as passed.

The current status is in [deliverable-status.md](deliverable-status.md). Build dependencies include the completed carrier PCB, component restraints, guards/interlock/linkage cover, source-matched collision and insertion checks, and Onshape integration. These are design work, separate from uncertainties that require hardware. Use [printing and assembly](printing-and-assembly.md), [calibration](calibration.md), [firmware operation](firmware-operation.md), [wiring](../hardware/wiring.md) and the [power budget](../hardware/power-budget.md) as the controlled references.

## Airflow design and what must be demonstrated

The axial head replaces two tilted fans and a turning plenum with one Noctua NF-A12x25 G2 PWM and a continuous inlet-to-outlet passage. Removing a bend and stream merge offers a plausible reduction in losses and turbulent mixing, but one fan has a different operating curve from two fans. The original version remains the comparison baseline if a prototype exists. Free-air volume, shutoff pressure and sound ratings do not occur simultaneously and do not predict the assembled product's performance.

| Starting geometry | Meaning and limitation |
|---|---|
| 114 mm throat, 14 mm bell-mouth radius | Throat area about 10,207 mm²; radius/throat-diameter ratio 0.123. The 142 mm mouth joins the throat with a true quarter-circle profile. It should reduce sharp-edge separation, but the printed finish, rear guard and nearby desk/wall can alter the benefit. |
| Circle-to-rounded-rectangle duct | A gradual transition to the 104 × 94 mm nominal outlet. Rounded corners and any local fillets reduce actual area slightly from the rectangular gross calculation. Check the generated sections rather than using only outer dimensions. |
| Seven radial vanes, 0.8 mm thick, 18 mm long | A compact trial straightener after an initial 15 mm separation from the fan's downstream envelope. Flat radial vanes can oppose tangential velocity, but their incidence, wake and blockage can also add loss and tones. This is not a measured swirl-matched stator. |
| Two 55 mm panels with one common yoke | Equal and opposite rotation forms a gradual height contraction. Linkages stay outside the main air path. Unlike planar shutter blades, the panels turn the wall inward along an axial length. |
| 104 × 94 mm open gross area | 9,776 mm² before grille blockage and boundary layers. The design seeks high normal-mode volume with the panels open. |
| Initial 75% minimum gross area | 7,332 mm², 70.5 mm exit height and 12.3355° inward panel angle. It is a starting test limit, not a demonstrated optimum. The firmware forbids reducing this ratio below 0.75. |

For width `W`, open height `H`, panel length `L` and inward angle `theta`, gross outlet area is `A = W × (H − 2 L sin(theta))`. In incompressible flow, mean axial velocity at a section is `Q/A`. If boost reduces area to 0.75 of open area, mean velocity improves only if the new volume flow remains above 0.75 of open volume. A provisional 10% velocity improvement requires `Qboost/Qopen > 0.825` at that area ratio. Real downstream jet measurements must also account for the fixed grille, spreading and velocity profile. A smaller opening alone does not establish useful boost.

The selected fan regulates speed. Restriction can substantially change flow while tach RPM remains near its commanded value. Use tach for motor diagnostics and an independent differential-pressure measurement for restriction supervision; neither replaces velocity/volume measurements. The existing wall tap measures a local static-pressure difference relative to ambient. It does not directly measure total pressure, fan efficiency or volume flow, and it can be biased by tap placement, swirl or blocked tubing.

## Measurement record and equipment

For each run, record CAD/source revision, firmware/UF2 hash, board revision, calibration record, fan/servo/LED board identity, print material/profile, configuration, ambient temperature, supply/cable, setup dimensions, instrument range/calibration and measurement uncertainty. Photograph the setup and keep raw samples. Repeat at least three settled readings per operating point, including an increasing and decreasing control sweep.

Use a differential manometer/reference within the sensor's useful low-pressure range, a suitably sized calibrated axial velocity probe or characterized low-pressure flow hood, an independent tachometer, a meter, an oscilloscope, a current measurement fixture/electronic load, contact thermocouples or another reference thermometer, a force gauge, angle gauge and calipers. For noise comparison use a calibrated sound-level instrument where possible; a phone recording is useful for identifying tones and rattles but is not an absolute sound rating. Keep temporary probes secured outside moving parts. Work with guarded hardware and an accessible electrical disconnect.

Log time series fast enough for the phenomenon: ordinary flow/thermal trends can use at least 10 samples/s and 1 sample/s respectively, while supply/PWM and short shutdown events need oscilloscope traces. Log controller state and commanded/measured position alongside measurements so a pressure-limited run is not mistaken for the requested full boost point.

## Bench sequence and aerodynamic comparison

1. Complete dry assembly and basic electrical commissioning. Measure both temperature channels, voltage scales, pressure zero/polarity, independent tach agreement and all five panel calibration points using the exact commands in [calibration.md](calibration.md). Do not disable guards or protections to make a test reach an intended setting.
2. Fix the fan head horizontal at its intended desk height. Leave a documented clear space around the inlet, initially at least one inlet diameter behind it, and a still-air measurement zone in front. Record nearby walls and desk reflections. Later repeat at realistic restricted inlet spacing; the clearance recommendation must come from these results.
3. With the full guarded enclosure and panels open, measure at normal power 25%, 50%, 75% and 100%, corresponding to 6, 12, 18 and 24 upward detents from zero. Also test the first nonzero detent and reliable starting from rest, rather than only reaching low power from high speed. After each setting change allow at least 10 seconds to settle; average stable data for a further 10 seconds. Extend the interval if pressure, RPM or velocity is still changing.
4. At normal maximum and verified open position, complete the separate 24-detent entry turn. Confirm the fan remains at maximum commissioned PWM and the panels remain open throughout entry, including its final detent. Then measure boost 0%, 25%, 50%, 75% and 100%, at 0, 6, 12, 18 and 24 additional detents. Reverse to zero boost and confirm that another full entry turn is required before closure can increase again. Record both panel angles, pressure mean/variation, RPM, input and servo current, velocity/volume, sound and any visible movement. Stop and correct rubbing, chatter or a pressure/fault event; do not increase thresholds to conceal it.
5. Repeat open and selected boost points with and without the trial straightener, maintaining identical fixed-guard support and all other geometry. Use a non-vane locating ring if needed for capture. Test a honeycomb only if measured residual swirl justifies a separate low-loss trial; it is not part of the default design.
6. Select the maximum useful closure from the measured tradeoff. Prefer a less-constricted endpoint when volume loss, pressure fluctuation, noise or jet nonuniformity increases without a repeatable throw benefit. Reduce closure through a larger `minAreaRatio`, then repeat the complete affected calibration evidence. The schema3 control uses normal maximum followed by a separate 24-detent / 360° entry turn and then 24 detents of boost adjustment. The stored 75% normal endpoint is an internal scaling parameter, not a boost trigger; preserve the deliberate full-turn entry gesture when tuning normal travel.

Measure a traverse plane beyond the grille with a grid covering the whole jet, including its low-velocity edges. Start with at least a 7 × 7 equal-area grid; refine around strong gradients and repeat with a finer grid until integrated flow changes less than the selected uncertainty allowance. Use the axial velocity component, not an omnidirectional speed magnitude in swirling flow. Estimate `Q = sum(v_axial,i × cell_area_i)` and report grid extent and probe blockage. A centreline reading multiplied by gross outlet area is not volume flow. A flow hood or collection duct changes system pressure unless characterized; compare its readings with/without the fixture and report the correction rather than assuming it is nonintrusive.

For useful throw, map the centreline and cross-jet profile at 0.25, 0.5, 1.0, 1.5 and 2.0 m, extending as needed. Use **1.0 m/s axial velocity** as an initial engineering threshold for reporting throw distance, and report jet width above that threshold at the same stations. This is a comparison metric, not a promised comfort specification. Repeat at the user's likely desk distance. A very fast centreline with a tiny useful area should not be described as improved overall airflow.

To assess swirl, use an instrument that resolves flow direction or a secured noncontact visualization method outside the guards. Compare tangential/axial flow or measured flow angle at matching radial points. Do not insert loose threads near the rotor. Retain the straightener only if the reduction in swirl or profile variation exceeds measurement uncertainty and its pressure/noise cost is acceptable. A provisional target is no more than 5% loss of normal volume flow and no more than 1 dBA added noise for a repeatable improvement in directionality. These are prototype decision criteria, not existing results.

The bell-mouth comparison should keep throat, fan, guards and downstream configuration constant. Use a sharp-edge or smaller-radius inlet trial only as a controlled sample, with guards fitted and no exposed rotor. Compare volume, inlet noise and near-lip flow behavior. Test radius changes within the available envelope and inspect whether the rear guard obstructs the rounded acceleration region. Do not run CFD on the modified impeller in Noctua's public integration CAD and present it as an accurate fan simulation.

## Provisional engineering acceptance matrix

These criteria are internal prototype targets. They are not product safety certification or manufacturer limits. Where an exact manufacturer limit applies, use the stricter supported limit and record it.

| Item | Measurement / initial acceptance |
|---|---|
| Normal airflow | Stable starts at minimum PWM across at least 20 cold/warm attempts; no contact or hunting. Report delivered volume at each normal point, with the assembled guards and grille. |
| Useful boost | At least 10% repeatable mean/centre-region axial velocity or throw improvement over normal maximum with the nozzle open, exceeding instrument uncertainty, while retaining at least 80% of open volume. Both measured values must be reported; the 10% mean-velocity target at 75% area may require more than 80% volume retention. If no endpoint meets a worthwhile tradeoff, reduce constriction and record the result. |
| Pressure margin | At the chosen endpoint, steady local pressure should remain below the 18 Pa soft limit by at least the larger of 2 Pa or measured uncertainty plus observed variation. No unexplained oscillation or repeated limiter cycling. Keep 24 Pa hard protection active. |
| Nozzle tracking | Both panels agree within 0.5° initially and return repeatably; no contact or clamp loosening over 100 slow manual/powered sweeps. Firmware feedback remains comfortably inside its trip tolerance, not just below it. |
| Servo capacity | Measure the worst manual yoke force with the fan off, then add analytical pressure load and gravity/acceleration allowances. Use the actual linkage mechanical advantage at each point. Target at least 3× margin to the supplier's 4.8 V stall torque as an initial screening check; stall torque is not a continuous rating. Also require acceptable current, temperature, noise and tracking in the endurance test. |
| Noise | Measure at 1 m on the outlet axis and at the intended user's position with fixed room geometry. Aim initially for normal full-power sound no greater than 35 dBA and boost increase no greater than 3 dBA, with no new tonal whistle, buzz or rattle. These targets may require revision based on achievable airflow. Background should be at least 10 dB below the measured fan level for a simple uncorrected comparison; otherwise report the limitation. |
| Grille retention | Test the actual four-pair gap and final skins/keepers, not catalog zero-gap magnet pull. Initial target: at least 5 N distributed axial retention, no spontaneous release/rattle during maximum operation, and intentional edge-peel removal below 15 N. A 24 Pa pressure over the gross open area is only about 0.235 N; handling, warping and keeper strength dominate. |
| Guard/cover rigidity | Use suitable guarded-access gauges and controlled static deflection tests on the fixed front/rear guards and linkage cover. Require no contact with rotor/linkage or detached fragment under the chosen handling load. Nominal 5–6 mm slots do not alone establish safe reach distance or impact resistance. Define applicable product-access qualification before a consumer release. |
| TPU isolation | Compare rigid and TPU mounting at matched settings with desk vibration/accelerometer and acoustic measurements. Require no contact/rattle or alignment loss. Measure pad thickness and fan alignment initially, after 24 hours assembled and after a hot run; permanent set must not consume rotor/duct clearance. |
| Encoder/base | Upward rim movement increases output, all detents count correctly, and axial pressing does not drag the wheel or bend its board. The base must not slide or tip during the measured approximately 6 N encoder press on the intended desk surfaces. Repeat after foot wear and cable loading. |
| Screen / ambient diffuser | Every screen test pattern and ambient pixel/color works, with no electrical contact with retainers or glare at the seated user's sightline. Confirm top-section power/boost/status bars, relative encoder angle and degrees-to-entry are legible. Test clear-window reflections and night brightness; essential fault indication must remain visible. |

## Power and temperature qualification

Verify a negotiated 15 V / at least 2 A PD contract before enabling loads. Measure fan voltage at its connector, logic at the actual load and servo voltage during motion. Fan voltage must stay below the selected fan's 13.2 V operating maximum; target its nominal 12 V. The firmware qualification ranges are 14–16 V bus and 4.65–5.35 V logic. Check supply current and regulator temperatures against the actual component limits and the [12.994 W analytical upper budget](../hardware/power-budget.md), including eight ambient pixels, the screen's provisional 100 mA allowance, the servo allowance and conversion losses. Measure the actual screen current at full backlight and patterns; 100 mA is not a manufacturer maximum.

Use an electronic load for the defined peak rail test rather than deliberately stalling a servo for a prolonged period. Test PD connection, startup ramp, maximum fan, fastest allowed servo motion, configured screen brightness and a bounded full-white ambient LED test. Also test full-backlight screen patterns. Observe current limiting, rail rise/fall, no MCU brownout and no unexpected PD renegotiation. Verify BUF2's buffered CS/RST/BL levels and power-off behavior. For BL the ideal network values are 3.748 V HIGH, 0.080 V LOW and 0.300 V with the buffer output disconnected; real buffer voltage drops and resistor/rail tolerances change these levels. Check darkness at night zero, cold connection, powered reset, watchdog restart and slow rail rise/fall, including behavior below the buffer's 4.5 V specified range. The fitted BSS138 identity is not published, so transistor threshold calculations do not establish zero visible light. A limiting eFuse can produce a sag before shutdown; record the waveform, not only a meter average.

Run the completed enclosure at its highest sustained commissioned operating point for at least two hours, and until every monitored hot spot changes less than 1°C over 15 minutes. Repeat at a documented warm ambient representative of intended use. Measure regulator packages/boards, load switches, eFuse region, fan motor area, connectors and adjacent printed surfaces with independent probes as well as both MCP9808 channels. TEMP1 must track the regulator hot region, while TEMP2 monitors fan/base air. Establish the offset between each sensor and the actual hot spot so 55°C warning and 65°C trip occur with useful margin. Move/couple a sensor if it measures unrelated air instead of the protected component.

Repeat a reduced-load run with the main fan stopped to establish that base ventilation does not depend on rotor flow. Any regulator thermal shutdown, softened support, connector discoloration, unstable rail, or temperature continuing to rise without margin is a failure. Correct the heat path, load or enclosure before raising software thresholds. The current design has no battery and no charging tests; the screen's top section reports power/service/fault status.
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

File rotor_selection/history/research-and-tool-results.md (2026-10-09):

# Original research and tool record

Exact retained calls and returned text from the study. Earlier truncated outputs remain marked as truncated.

## Call 3: exec — 2026-10-09T16:15:15.748Z

````text
const r = await tools.exec_command({cmd:"rg -n -i \"Windflow|motor|fan|boost\" 'C:\\Users\\admin\\.codex\\memories\\MEMORY.md'","max_output_tokens":5500});text(r.output);
const s = await tools.exec_command({cmd:"rg --files -g AGENTS.md -g '*motor*' -g '*fan*' -g '*.md' -g '*.json' -g '*.csv' -g '*.yaml' -g '*.toml'","workdir":"C:\\Users\\admin\\iCloudDrive\\Windflow","max_output_tokens":7500});text(s.output);
text(ALL_TOOLS.filter(x=>/search|onshape|blender|pages|visual/i.test(x.name+" "+x.description)).map(x=>({name:x.name,description:x.description.substring(0,220)})).slice(0,100));

````

## Result 4 — 2026-10-09T16:15:18.019Z

````text
Script completed
Wall time 2.1 seconds
Output:

````

````text
Warning: truncated output (original token count: 10443)
Total output lines: 183

63:- Keep significant behavior; "a button that when pressed once makes the drive at 70% velo and when pressed again goes to 100 (starts match on 70)" -> start each driver period at 70%, use Right-arrow edge detection, and keep controller averages alongside individual Brain motor rows. "I still want the nlcs drive though, as it was before" -> preserve both NLCS and Bedford when branching. [Task 1]
68:- Bedford drive.v5python is the enhanced variant; nlcs drive.v5python is restored to its 357-line pre-change behavior. Use rising-edge toggle, update remembered state, scale both drivetrain outputs, read ten named motors numerically before six-drive/four-lift averages, and avoid row or tuple temperature calls. Pair lives under code/VEXCODEV5/drive/2026-09/. [Task 1]
170:# Task Group: Windflow Rev B engineering and workstation integrations
172:scope: Continue the screen/boost interaction, local CAD/electronics studies, evidence-matched assembly validation, or prepared Blender/Bambu/Onshape FeatureScript integrations.
173:applies_to: cwd=C:\Users\admin\iCloudDrive\Windflow; reuse_rule=regenerate source-matched reports after geometry changes; local CAD/software results are not physical or current-Onshape qualification, and printer control needs explicit authorization.
179:- rollout_summaries/2026-09-08T20-44-35-XAFw-windflow_screen_full_turn_boost_rev_b_integration.md (cwd=\\?\C:\Users\admin\iCloudDrive\Windflow, rollout_path=\\?\C:\Users\admin\.codex\sessions\2026\10\03\rollout-2026-10-03T11-53-34-01a082c3-f6b3-77a2-b642-16afc9a7a406_01a10165-d9a1-7fb0-9819-40f28882b7ae.jsonl, updated_at=2026-10-05T20:14:53+00:00, thread_id=01a082c3-f6b3-77a2-b642-16afc9a7a406, local integration only)
185:## Task 2: Full-turn boost-entry firmware/UI contract, focused software success
189:- rollout_summaries/2026-09-08T20-44-35-XAFw-windflow_screen_full_turn_boost_rev_b_integration.md (cwd=\\?\C:\Users\admin\iCloudDrive\Windflow, rollout_path=\\?\C:\Users\admin\.codex\sessions\2026\10\03\rollout-2026-10-03T11-53-34-01a082c3-f6b3-77a2-b642-16afc9a7a406_01a10165-d9a1-7fb0-9819-40f28882b7ae.jsonl, updated_at=2026-10-05T20:14:53+00:00, thread_id=01a082c3-f6b3-77a2-b642-16afc9a7a406, host/build evidence only)
193:- Control.cpp, RotaryMode, entryDetentsRemaining, 24 detents, boostEntryReady, markChanged, 6,649 host assertions, RP2040
195:## Task 3: Grille/fan/Pico/encoder/carrier/pressure studies, partial
199:- rollout_summaries/2026-09-08T20-44-35-XAFw-windflow_screen_full_turn_boost_rev_b_integration.md (cwd=\\?\C:\Users\admin\iCloudDrive\Windflow, rollout_path=\\?\C:\Users\admin\.codex\sessions\2026\10\03\rollout-2026-10-03T11-53-34-01a082c3-f6b3-77a2-b642-16afc9a7a406_01a10165-d9a1-7fb0-9819-40f28882b7ae.jsonl, updated_at=2026-10-05T20:14:53+00:00, thread_id=01a082c3-f6b3-77a2-b642-16afc9a7a406, current assembly verification incomplete)
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

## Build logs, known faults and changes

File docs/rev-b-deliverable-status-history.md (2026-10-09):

# Deliverable status — 5 October 2026

**Supersession notice, 6 October 2026:** the active motor, impeller, ESC, power and flowing-head redesign is Rev C. See [its implementation plan](rev-c-implementation-plan.md), [motor and power specification](rev-c-motor-power.md), [impeller](rev-c-impeller.md) and [firmware](rev-c-firmware.md). The register below records the earlier Rev B state. Its assembly clearance results and 12 V fan circuit are not evidence for Rev C. Current native Onshape and local Rev C geometry are development artifacts; purchased-component integration, retention, guards, mechanism details and whole-assembly validation must be completed before print release.

This is a progress register, not a manufacturing release or completion certificate. Onshape access and file upload are working. The original design is preserved in its baseline version. The latest user revision replaces the two main LED sticks and status lamp with a 320 x240 IPS screen, retains downward ambient lighting, and requires a full encoder revolution before each boost session. Current engineering work includes that concrete CAD, firmware and electrical integration.

| Required deliverable | Current artifact / status |
|---|---|
| Updated Onshape CAD | Native inlet, stator and progressive-nozzle study regenerate as five parts. The [3 October IPS screen checkpoint](https://cad.onshape.com/documents/5ca1b5b26cd9a4a93dde4737/w/6d3d38529391b53ad011b362/e/9ee256003ae02b710e21a9ec) contains 76 imported instances and passed local/native nominal interference checks for that revision. Subsequent local fan-stack, Pico-mount, encoder-board and interlock changes require a fresh complete-assembly check and import. Independent carrier and encoder board studios exist; these do not update the older assembly automatically. Motion mates and other interfaces remain unfinished. |
| Purchased CAD integration | Manufacturer models for the fan, Pico, PD board, regulators, temperature boards, pressure sensor and the ambient LED stick have vendor-model integration. The new 4311 display has a 15-solid manufacturer model placed in local E3 CAD; the current rear EYESPI connector/pigtail still needs a physical fit check. Servo and encoder remain drawing-based envelopes. See `cad/model-register.md`. |
| Complete firmware | Current E3 modular source and compiled UF2 in `firmware/`; 41,311 control assertions, 185 display-view assertions, 227 production service-command assertions and 384,000 exact production-GFX pixel comparisons pass with exit 0. Final Pico build passes. No physical device flashed or commissioned. |
| Exact BOM and nonprinted components | `hardware/BOM.md`, electrical revision E3: Adafruit 4311 screen and 8 ambient pixels replace the former main/status bars. The corrected fan stack, M1.6 Pico mounts and 5 V grille-contact buffer are specified. Main-carrier capture, pressure routing and complete product fastener reconciliation remain open. |
| Wiring diagram / pin assignment | `hardware/wiring.md` contains a net-level diagram and exact Pico physical pins. BUF2 now buffers CS/reset/BL; the BL correction uses R56=1k and new R59=100k input pulldown. It is not a captured schematic or routed carrier PCB; reset/night darkness remains unmeasured. |
| Power budget / USB-C architecture | `hardware/power-budget.md`, `hardware/circuit-review.md`: 15 V / 2 A PD, regulated rails, no battery. Calculated allowances need measurement. |
| Airflow / bell-mouth / straightener | Parametric native and local geometry: 114 mm throat, 14 mm inlet radius, seven trial radial vanes. Performance remains unmeasured. |
| Progressive boost / mapping | One servo, symmetric panels and yoke. Normal 0–100% uses 24 detents and stays open; 24 entry detents (360 degrees) at maximum enable a separate 24-detent progressive boost range. Returning to zero boost exits and resets entry. Initial 75% minimum gross outlet area. Native aerodynamic study and integrated mechanical model have separate purposes. |
| Thermal / tach / startup logic | `docs/firmware-operation.md`: implemented and host-tested. Sensor placement/lag, tach signal and safety response require hardware qualification. |
| Calibration instructions | `docs/calibration.md`: measured commissioning evidence is required before enabling live boost. |
| Printing instructions | `docs/printing-and-assembly.md` plus fit coupons. Large-part release awaits integration, tool/harness review and slicer/coupon acceptance. |
| Assembly instructions | Split head and separate keyed cranks have an explicit insertion sequence. Sensor mounts, optical retainers and linkage cover exist. Carrier/harness/interlock integration still needs completion. |
| Physical tuning and uncertainties | `docs/physical-validation.md`, mechanism notes and calibration distinguish tuning values from measured results. No physical qualification is recorded. |

## Verified evidence and its limits

- Current E3 firmware: 41,311 control assertions, 185 display-view assertions, 227 production service-command assertions and 384,000 exact production Adafruit_GFX pixel comparisons, each with exit 0. Final Pico compilation exits 0: 121,460 program bytes, 11,112 static RAM bytes, plus a 10,240-byte heap canvas. These are source/build/render results, not attached-electronics testing.
- Current display service path: 174 samples, zero unintended intersections, exit 0; generator hashes match the checked sources. The sequence removes the front bezel/window, pulls the unplugged cradle rearward 2 mm and lowers it through the bottom after tray removal. The check excludes screws, tools, harness and tolerances. Bezel uses four RX-M2x4 inserts rather than tapped PETG.
- Display fastener supplement: twelve nominal ISO 4762 screw-head/rear-tip envelopes clear the installed base components with exit 0. This does not check intentional thread/insert engagement, hand access, a complete driver sweep or tolerance extremes.
- Onshape: native airflow studio shows seven features and five parts. Nozzle boost fractions 0, 0.5 and 1 regenerate; a 0.5 minimum area ratio is rejected by the 15 degree angle ceiling. Saved setting: 0 boost, 0.75 minimum area. This study does not drive the imported structural shell automatically.
- Housing import: exact eight-arc circular throat loft replaces the near-circle sliver geometry. Left and right halves each show one part with **Allow faulty parts unchecked**. Proof images are under `cad/evidence/`.
- Local mechanism fixture: 61 nominal positions, zero unintended overlap. Thirteen sampled insertion paths pass with exit 0 after changing crank approach to vertical. The insertion model excludes fasteners, servo, wiring, guards and tools installed later.
- The revised local base generator passes its support/component checks, and the display service check passes against that regenerated base. The interlock is being adopted in the head. No current whole-assembly pass is claimed until all adopted geometry is rebuilt and source/input hashes match a new report.
- The **3 October E3 checkpoint** passed with exit 0: **76 components, 5,536 pair checks and 183 cover-removal samples** across open/halfway/maximum boost, with zero unintended intersections. Its imported STEP SHA256 is `9e377ef335463d43efa9764526675d6dbd54f98391e9d279571e6ecb914d7159`. That report is historical evidence for that checkpoint, not the subsequently changed workspace geometry. It excludes complete fastener, harness, tool and tolerance validation.
- The 3 October Onshape checkpoint has 76 instances and seven native interference entries: six are internal contacts within the vendor HUSB238 model, and one is intentional encoder/thumbwheel engagement. No other findings were reported for that revision. These imported nominal solids do not establish motion mates, print tolerances or physical assembly qualification.
- Encoder PCB P1: editable native schematic and routed two-layer board, exact four-net pin checks, zero ERC/DRC/unconnected/parity findings and clean command exits. Its independent [Onshape datum studio](https://cad.onshape.com/documents/5ca1b5b26cd9a4a93dde4737/w/6d3d38529391b53ad011b362/e/21041dd778175eaad866a4ab) visibly contains one part. Actual seating, soldering and thumbwheel force remain physical checks.
- Grille interlock study: 18,737 nominal checks, 61 panel poses, 5,002 panel comparisons and eight driver approaches pass with clean exit 0. The documented solder/TPU compression contacts are intentional. The study uses frozen inputs and requires main assembly adoption, base continuation and physical overtravel/contact tests.
- Nominal gross outlet area is 9,776 mm² open and 7,332 mm² at the initial limit. These dimensions establish a geometric contraction, not higher measured jet speed or throw.

## Engineering still required before physical qualification

1. Complete assembly motion mates, harness and tool-access review. Recheck and import the newly adopted fan stack, Pico mounting, encoder PCB and grille interlock. The 76-instance E3 import is an older checked checkpoint; populated service paths and tolerance extremes remain open.
2. Adopt the carrier-to-Pico/regulator physical interconnection. The native 90 × 65 × 1.6 mm mechanical PCB has four matching NPTH holes and enforced mounting keepouts; it passes 23 native checks, zero-violation baseline DRC and three deliberate negative keepout probes. Its independent Onshape studio contains one part. It has no electrical circuit. The separate keyed ribbon study passes 555 nominal checks against the revised base, but still needs bend, clamp and service-slack validation. See `hardware/pcb/carrier-mechanical/README.md` and `hardware/carrier-interface-study.md`.
3. Finish the captured main-carrier circuit, route its PCB, run ERC/DRC and generate fabrication/placement files. The encoder board is routed and checked; the direct-solder pressure daughterboard is being captured and routed.
4. Complete pressure-tap hose connection, tube path, grille-present switch mount/contact interface, wiring restraints and service slack. Resolve the fan compression-limiter/pad interface and model its actual stack.
5. Reconcile final fastener quantities and demonstrate tool access and populated-tray removal. Run final source-matched interference and insertion checks after those changes.

These are unfinished design tasks, not merely uncertainties delegated to physical testing. Airflow, noise, finger access, magnetic retention, print fit, servo friction, fault timing, thermal behavior and USB margins remain separate physical qualification work.

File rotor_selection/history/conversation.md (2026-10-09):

# Original rotor-selection conversation

Saved verbatim user-facing text from the original study, including the layout approval.

## User — 2026-10-09T16:15:07.385Z

Analyse different fan shapes with the target being the fastest airspeed. The total fan has a max height of 200mm. Remember the motor which I am using, so you need to pick a fan shape that utilises the full capability of it. Boost mode should still need to have a noticeable impact. The sound should be minimised as much as possible, since a larger rotor will produce the same airflow at a lower RPM compared to a smaller rotor, this should be smoothly integrated into the other targets

## Assistant — 2026-10-09T16:15:11.658Z

I’ll check the motor specification and current fan design, then compare rotor shapes against airspeed, the 200 mm height limit, noise, and a noticeable boost mode. I’ll also check where a larger rotor helps—and where it could exceed the motor’s useful operating range.

## Assistant — 2026-10-09T16:16:35.534Z

The current design uses your **T-Motor Pacer V4 P2406 Juicy 2060KV**, with an A50S controller and an **18 W motor-plus-controller input limit**. That power limit matters more here than the motor’s published 1,116 W one-second drone peak.

A larger rotor can reduce RPM for the same airflow, but it also needs more torque and may produce less pressure. I’m checking the complete height—including the inlet and electronics base—so the recommendation leaves room for both useful airspeed and boost.

## User — 2026-10-09T16:17:16.689Z

<send_user_message_question_reply>
[{"questionItemId":"[\"request_user_input_async\",\"call_33fcda7425b14c02aaf2e2806a7522d4\",0]","question":"For the 200 mm total height limit, may I rearrange the electronics base and inlet to fit a larger rotor while keeping the existing screen and controls?","answer":"Yes—optimise the whole layout within 200 mm"}]
</send_user_message_question_reply>

## Assistant — 2026-10-09T16:18:51.573Z

With the layout allowed to change, a **roughly 150 mm rotor** is a practical candidate. The current local assembly report puts the feet-to-linkage-cover height at about **215.9 mm**, so the layout needs revision even before enlarging the rotor.

I also found a motor-matching issue: at the current **3 A phase-current limit**, this high-KV motor has only roughly **4 W of shaft-power capability at 3,000 RPM**, depending on current convention and losses. A larger rotor therefore needs a qualified torque limit as well as a good blade shape; the 18 W electrical budget alone won’t make it perform.

## Assistant — 2026-10-09T16:24:08.017Z

The comparisons point to a **150 mm swept, twisted axial rotor with five blades** as the best first candidate. A mixed-flow rotor is the strongest alternative if the outlet restriction makes the axial design lose too much flow.

The calculations also show why simply scaling up the current rotor won’t work: a geometrically similar 150 mm fan can match its airflow at about **1,250 RPM**, but would retain only about **31% of its pressure capability** at that point. I’m building the recommendation around pressure as well as airflow, with a proposed **195 mm height budget** and measurable targets for boost.

## Assistant — 2026-10-09T16:30:26.549Z

**I recommend a 150 mm, five-blade ducted axial rotor with broad, cambered, twisted and moderately swept blades**, combined with a rounded inlet, a matched downstream stator and a smooth adjustable outlet. It is the strongest first candidate for combining high useful airspeed, quiet normal operation and a noticeable boost within your **200 mm total height**.

The strongest competing shape is a **mixed-flow rotor**, which combines axial and radial flow. It could outperform the axial design if the outlet contraction demands more pressure than the axial rotor can provide efficiently. The available evidence supports this development choice; it does not yet establish a measured fastest or quietest winner.

I’ve saved the [full analysis and calculations](/C:/Users/admin/iCloudDrive/Windflow/docs/fan-shape-analysis-2026-10-09.md), including the motor matching, diameter comparisons, height budget and boost targets.

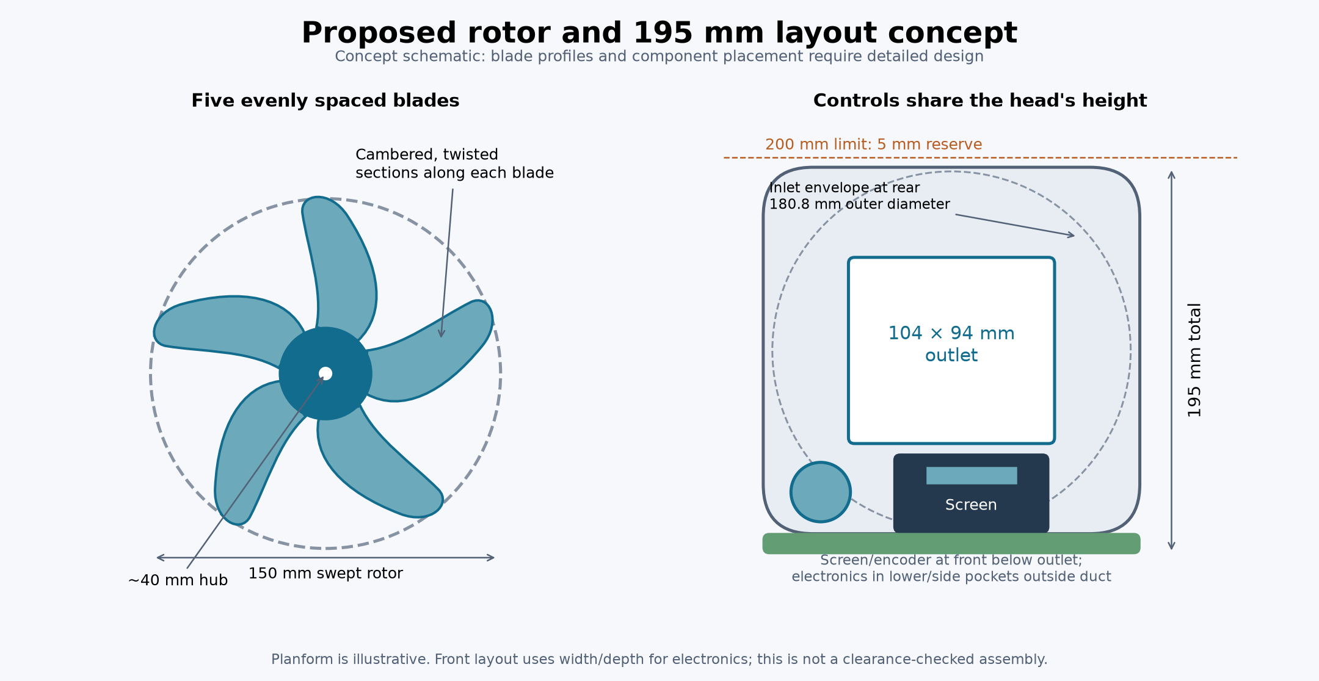
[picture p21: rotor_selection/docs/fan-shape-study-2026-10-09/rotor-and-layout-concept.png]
Proposed rotor shape and complete-product layout concept


*This is a concept schematic. The blade sections and revised component placement still need detailed design.*

Your motor is the **T-Motor Pacer V4 P2406 Juicy 2060KV**. Its published **1,116 W rating is a one-second peak** under drone conditions. Your current desktop architecture supplies the motor and A50S controller through an **18 W input limit**, so the design should use its capability within that electrical and thermal envelope. Using its entire published peak would require a substantially different power system. [Motor specification](https://www.ligpower.com/product/p2406-fpv-freestyle-motor.html).

The shape comparison favours the following options. These are engineering assessments of the complete fan stage, rather than measured performance rankings. Pressure demand and flow separation are central to choosing between axial, mixed-flow and centrifugal designs. [Manufacturer’s explanation of fan architectures](https://mag.ebmpapst.com/en/insights/axial-diagonal-centrifugal_2447/).

| Fan shape | Effect on your targets | Assessment |
|---|---|---|
| Two or three narrow propeller blades | Good unrestricted flow, but harder to maintain flow through a guarded, contracted outlet at low RPM | Poor first choice for effective boost |
| **Five broad, swept and twisted axial blades** | Balances blade loading, pressure capability, drag and a direct airflow path | **Recommended starting shape** |
| Seven swept axial blades | Can distribute loading and improve pressure performance; sound depends on total blade area and blade–stator interaction | Main blade-count comparison |
| **Mixed-flow rotor** | May retain more flow as the outlet contracts, giving stronger useful airspeed | **Primary alternative** |
| Backward-curved centrifugal impeller | Strong pressure potential for a narrow jet; needs a scroll and a different airflow layout | Worth considering if concentrated jet speed dominates |
| Many-blade, high-speed EDF shape | High-speed jet emphasis, with greater potential for intrusive tones | Low priority for quiet desktop use |

**The motor’s torque limit needs attention before increasing diameter.** Your current initial limit is **3 A of motor phase current**. A rough calculation from the motor’s KV gives approximately **3.8–4.4 W of electromagnetic power at 3,000 RPM**, before friction and core losses. The range reflects different current conventions; it is not a measured torque map for your controller. [Torque-constant convention reference](https://newdocs.odriverobotics.com/v/latest/guides/odrivetool-setup.html).

That means the motor can reach its current limit well before delivering useful power comparable to the 18 W electrical budget. For perspective, producing **10 W at 2,500 RPM** would require roughly **8–10 A** under those illustrative conventions, before loss compensation. Those figures identify what needs qualification; they are not new ESC settings to apply. If 3 A must remain the permanent limit, a **125–140 mm rotor** deserves comparison because a large, slow rotor could become torque constrained.

Your larger-rotor reasoning is correct for airflow, but pressure must be included. For geometrically similar fans, enlarging a 112 mm rotor to 150 mm could match its airflow at about **1,250 RPM instead of 3,000 RPM**. However, it would retain only about **31% of the pressure capability** at that corresponding point. This is a scaling illustration, not the proposed rotor’s operating speed. [Fan scaling laws](https://beckettair.com/resources/fan-laws/).

The 150 mm design therefore needs blades that maintain flow through the outlet. Simply enlarging the current blades and lowering RPM would risk weakening boost. Equally, running the larger rotor at the same RPM increases tip speed and loading, so larger diameter alone does not establish quieter operation.

For noise reduction, I would integrate these features into the selected shape:

- **Spanwise twist and camber**, so each part of the blade works at a suitable angle instead of using one flat pitch.
- **Broad mid-span sections with gradual tip taper**, balancing pressure capability against drag.
- **Moderate sweep**, compared against an unswept version at equal useful output.
- **Smooth leading edges and consistently finished trailing edges**; the current printed tip sections have relatively blunt trailing edges.
- **A stator matched to the rotor’s swirl**, with streamlined motor supports and suitable spacing.
- **A rounded inlet, flush internal joints and a controlled tip gap**, reducing disturbances before and around the rotor.

Tip leakage and its interaction with the housing are established noise sources, but their improvement cannot be assigned a reliable dBA value for this prototype without measurement. [Blade-tip noise mechanisms](https://mag.ebmpapst.com/en/products/fans/the-formula-for-vorticity_11766/).

**Boost should use both a reserved speed range and the outlet contraction.** The current control uses the same maximum rotor speed in normal and boost modes, so its boost benefit depends entirely on how much flow survives the smaller outlet.

At the current **75% outlet-area endpoint**, continuity gives:

| Flow retained after closure, at the same RPM | Average outlet airspeed increase |
|---|---:|
| 100% | +33.3% |
| 95% | +26.7% |
| 90% | +20.0% |
| 80% | +6.7% |
| 75% | No increase |

I would reserve roughly **15–20% of the qualified maximum RPM above normal maximum**, then coordinate that reserve with the measured beneficial panel travel. Keep the fresh full encoder turn to arm boost. Set an acceptance target of **at least 20%, preferably 25–30%, higher average outlet velocity than normal maximum**, with a useful increase still apparent at 0.5 m. These are proposed targets, not predicted results.

For packaging, I propose a **195 mm total height budget**: a 185 mm head envelope including the inlet, guards and linkage, plus 10 mm of base/feet extension. A 150 mm rotor, 152 mm throat, 12 mm inlet radius and 2.4 mm wall give an inlet outer diameter of **180.8 mm**. The screen and encoder would occupy the front lower portion below the outlet, while electronics use lower and side pockets outside the air duct.

The current source-matched local assembly report reaches about **215.9 mm from feet to linkage cover**, so rearrangement is necessary even before enlarging the rotor. The proposed 195 mm layout leaves 5 mm of height reserve, but its revised 3D fit remains unverified.

The saved study includes checked calculations and two inspected diagrams. **Absolute airspeed, sound level and the final winning shape remain unmeasured**: selecting them requires comparing the complete stages at equal useful output and at their qualified maximum power. The 150 mm five-blade axial stage is my recommended first design, with mixed-flow as the serious pressure-focused comparator.

<oai-mem-citation>
<citation_entries>
MEMORY.md:247-248|note=[preserved boost interaction and checked current source evidence]
rollout_summaries/2026-09-08T20-44-35-XAFw-windflow_screen_full_turn_boost_rev_b_integration.md:9-9|note=[recovered prior screen and full-turn boost requirements]
</citation_entries>
<rollout_ids>
01a082c3-f6b3-77a2-b642-16afc9a7a406
</rollout_ids>
</oai-mem-citation>

## User — 2026-10-09T16:44:29.393Z

<external_codex_apps_open_page>{"page_id":null}</external_codex_apps_open_page>

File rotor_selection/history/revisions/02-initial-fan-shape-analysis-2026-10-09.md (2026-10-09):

# Windflow fan shape, airspeed and noise study

9 October 2026. Analytical design selection for the existing P2406 motor. The user permits rearranging the inlet and electronics base, retaining the screen and controls, within a **200 mm complete product height**.

**Recommended first candidate: a 150 mm, five-blade ducted axial rotor with cambered, twisted, moderately swept blades, a rounded inlet, a matched outlet stator and a smooth adjustable contraction.** Design the rotor for the pressure required by the outlet, rather than enlarging a free-air propeller. Use a mild mixed-flow rotor as the primary competing design if the axial stage loses too much flow under contraction. This is an engineering selection to develop and compare; no measured curve establishes a fastest or quietest winner yet.

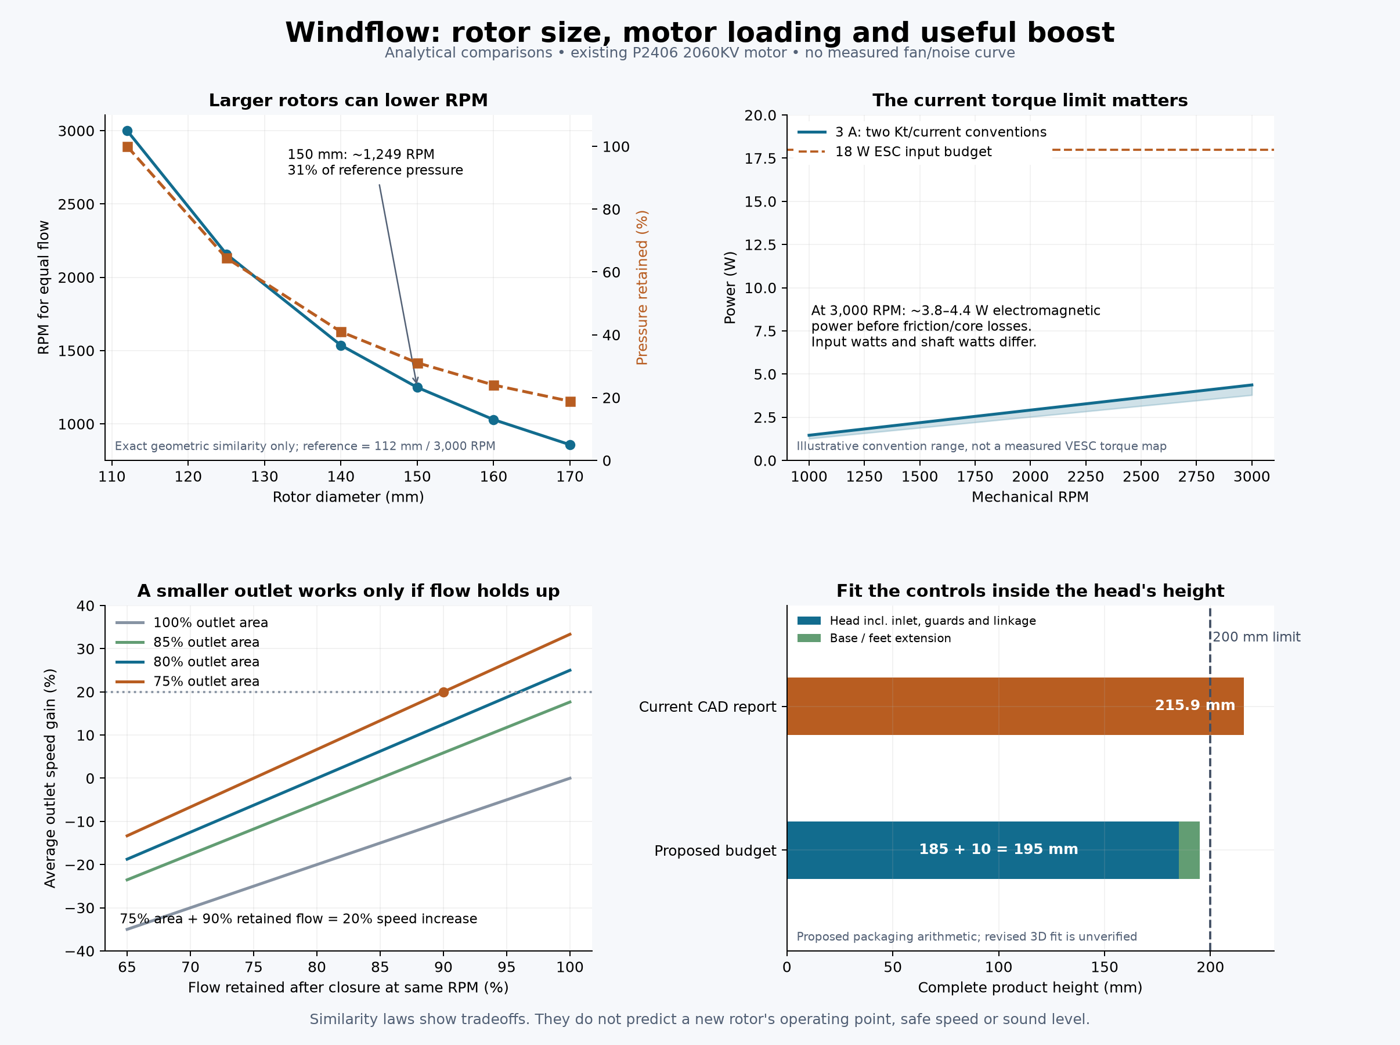
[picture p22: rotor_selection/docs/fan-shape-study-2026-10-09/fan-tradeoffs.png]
Calculated size, loading, boost and height tradeoffs


## Existing motor and actual constraints

The current files specify the **T-Motor / LIGPOWER Pacer V4 P2406 Juicy 2060KV**, not the historical packaged Noctua fan. Its manufacturer gives a 30.2 mm diameter, 31 mm axial envelope, M5 propeller shaft, four M3 mounting holes on a 16 mm pitch circle, and 12N14P configuration. The published 48 A / 1,116 W figures are **one-second peaks at drone operating conditions**; they do not establish a continuous desktop rating. The motor's published propeller data are around 9,600–33,000 RPM, far above the proposed desktop regime. [Motor specification and test data](https://www.ligpower.com/product/p2406-fpv-freestyle-motor.html).

The active architecture uses an **A50S V2.3c controller**, 15 V / 3 A USB PD, an **18 W ESC-plus-motor input cap**, an initial **3 A phase-current cap**, and a 3,000 RPM guarded commissioning ceiling. The separate 5,000 RPM calculation is not operating qualification. The ESC supports sensorless FOC and speed control; its 20 A advertised motor-current capability does not qualify this motor, wiring or rotor for that current. [ESC specification](https://teamtriforceuk.com/a50s-v2/), [current local electrical specification](../hardware/rev_c/motor-esc-specification.json), [power architecture](rev-c-motor-power.md).

At 15 V, KV × voltage gives approximately 30,900 RPM ideal no-load speed. This is neither the desired speed nor a usable full-throttle command for a large desktop impeller. Full useful capability means using the **qualified torque, power and thermal envelope** efficiently. Using the motor's entire published peak would require a different supply and a different product design.

### The phase-current limit can dominate before the 18 W limit

A first motor-matching estimate uses torque = Kt × current and mechanical power = torque × angular speed. Two common current/voltage conventions give illustrative Kt values of **8.27 / 2060 = 0.00401** and **9.55 / 2060 = 0.00464 N·m/A**. The first is documented by ODrive for its phase-current convention; the second is the SI reciprocal of a speed constant. This bracket is **not a tolerance band or a calibrated conversion for the A50S/VESC**. Motor identification and torque/current measurements must resolve the applicable convention. [ODrive torque-constant guidance](https://newdocs.odriverobotics.com/v/latest/guides/odrivetool-setup.html).

| Rotor speed | Electromagnetic power estimate at 3 A, before friction/core losses | Illustrative current for 10 W shaft output, before loss compensation |
|---|---:|---:|
| 1,500 RPM | 1.89–2.18 W | 13.7–15.9 A |
| 2,000 RPM | 2.52–2.91 W | 10.3–11.9 A |
| 2,500 RPM | 3.15–3.64 W | 8.2–9.5 A |
| 3,000 RPM | 3.78–4.37 W | 6.9–7.9 A |

These estimates show why a large rotor cannot be promised 18 W of useful shaft power with the present 3 A setting. Supply current, phase current and shaft power are different quantities. Keep 3 A as the existing initial limit; qualify a revised torque/current envelope before expecting the larger rotor to use more of the electrical budget. The illustrative currents above are **design requirements to investigate, not controller settings to apply**. The motor's high-speed idle-current figure cannot be treated as a constant loss at low speed.

If the 3 A cap must remain permanently, compare a 125–140 mm axial rotor as well: the larger 150 mm design may lose its advantage when the pressure requirement forces more torque than is available. A smaller rotor at higher speed can access more mechanical power at the same torque cap, with a potential noise penalty. No geared drive is proposed: its added noise and the motor's high-speed losses need separate justification.

## What “fastest airspeed” means for this selection

Rank designs primarily by **area-average outlet velocity** with the complete guards, stator and nozzle fitted, at equal available electrical/thermal limits. Also measure centerline velocity and the velocity profile at 0.5 m and 1 m. A tiny local high-speed spot should not outrank a useful, stable jet.

Average velocity is Q / A. Maximizing flow alone, RPM alone, or pressure alone will not maximize useful outlet velocity. The complete fan curve and the inlet/guard/stator/nozzle resistance determine Q. Exit speed and downstream throw also differ because entrainment and jet spreading change the profile.

Compare noise both **at equal useful outlet speed** and at each design's maximum allowed output. The first comparison identifies aerodynamic/acoustic efficiency; the second shows the cost of ultimate performance. Record A-weighted sound plus narrow-band or one-third-octave data so an intrusive tone cannot disappear inside one overall number.

## Shape comparison

These are reasoned architectural expectations, not measured rankings or numerical performance predictions. The fan manufacturer describes pressure requirement and separation as decisive in choosing axial, diagonal and centrifugal designs. [Architecture and pressure explanation](https://mag.ebmpapst.com/en/insights/axial-diagonal-centrifugal_2447/).

| Shape | Fit to airspeed and boost | Noise/loading considerations | Selection |
|---|---|---|---|
| Two/three narrow, propeller-like blades | Good low-restriction flow; limited solidity makes pressure demand harder to satisfy at low RPM | Low blade count does not guarantee low sound; greater loading per blade and higher required speed can create strong pulses | Comparator only; poor first choice for a contracted guarded outlet |
| Five broad, cambered, twisted, moderately swept axial blades | Direct flow path, useful pressure potential and enough blade area without excessive solidity | Balance between blade loading, profile drag and interaction tones; needs clean inlet, finished edges and a matched stator | **Preferred first candidate at 150 mm** |
| Seven narrower swept axial blades at similar total solidity | Can distribute loading and improve the usable pressure range, depending on section design | More blades shift blade-passing frequency upward; equal total solidity matters; either better or worse acoustics is possible | Main blade-count comparison |
| Mild mixed-flow / diagonal rotor | Adds a radial component that may retain flow better through the contraction | Can combine pressure and noise advantages when designed as a complete stage; conical hub/shroud and flow return add complexity | **Primary alternative if axial boost flow collapses** |
| Backward-curved centrifugal impeller with scroll and outlet | Strong candidate for pressure and a deliberately narrow jet | Scroll/tongue/inlet interactions and turning losses need tuning; a well-designed blower can be quiet, but the existing axial layout cannot simply accept it | Reconsider if maximum narrow-jet speed outweighs the present layout and broad-flow goal |
| Many-blade, high-speed EDF-style rotor | Pressure/high-speed jet focus | Higher speed and tonal content conflict with the quiet desktop objective; torque/18 W limit still applies | Low priority |
| Cross-flow cylindrical rotor | Broad, even slot flow | Different scroll geometry and motor loading; not the natural first choice for concentrated forward airspeed | Low priority |

Commercial mixed-flow results demonstrate that greater pressure does not inevitably mean greater noise. Their measured benefits cannot be transferred numerically to this printed prototype. [Manufacturer's mixed-flow example](https://mag.ebmpapst.com/en/industries/electronics/diaforce-diagonal-fan-combines-axial-and-centrifugal-in-one-fan_14990/).

## Diameter: lower RPM must retain enough pressure

For geometrically similar fans at corresponding operating points and approximately equal efficiency:

`Q ∝ N D³`, `Δp ∝ N² D²`, `Pshaft ∝ N³ D⁵`, `Tshaft ∝ N² D⁵`.

At equal flow, this gives `N ∝ D⁻³`, `Δp ∝ D⁻⁴` and `Tshaft ∝ D⁻¹`. Thus a simply enlarged fan does **not** automatically need more torque at equal flow: its pressure and power have also fallen. At the **same required flow and pressure**, useful air power remains Q × Δp; lower RPM then demands more torque for the same shaft power. [Fan laws](https://beckettair.com/resources/fan-laws/), [geometric-similarity assumptions](https://ansyshelp.ansys.com/public/Views/Secured/MotorCAD/v252/en/Motor-CAD_UG/MotorCAD/topics/airflow.html).

| Diameter | RPM to match the flow of a similar 112 mm fan at 3,000 RPM | Tip speed at that point | Pressure retained at that point | Shaft power multiplier if instead kept at 3,000 RPM |
|---|---:|---:|---:|---:|
| 112 mm | 3,000 | 17.6 m/s | 100% | 1.00× |
| 125 mm | 2,158 | 14.1 m/s | 64% | 1.73× |
| 140 mm | 1,536 | 11.3 m/s | 41% | 3.05× |
| 150 mm | 1,249 | 9.8 m/s | 31% | 4.31× |
| 160 mm | 1,029 | 8.6 m/s | 24% | 5.95× |
| 170 mm | 858 | 7.6 m/s | 19% | 8.06× |

This is a scaling demonstration, **not an RPM schedule for the actual new rotor**. Keeping the same motor, a 40 mm hub and the same outlet breaks exact geometric similarity. The 150 mm selection is a compromise: appreciably more area than the current 112 mm rotor, while leaving room for the inlet and a pressure-capable stage. A 160–170 mm rotor increases packaging and torque/pressure-design difficulty without a demonstrated useful-speed advantage.

At the same 3,000 RPM, a 150 mm tip moves at 23.6 m/s, faster than the present 112 mm rotor's 17.6 m/s. **Larger diameter is quieter only when the required operating speed and aerodynamic loading permit it.** Compare complete stages at equal useful output.

## Proposed blade and stage geometry

Use five evenly spaced blades as the baseline, and seven blades with comparable total solidity as the comparison. Avoid choosing a count from appearance or assuming relatively prime rotor/stator counts eliminate noise.

- **150 mm rotor; approximately 40 mm hub.** The hub-to-tip diameter ratio is 0.267, leaving about 93% of disk area outside the hub. Preserve the purchased motor/shaft interface and keep root reinforcement out of the main working span.
- **Cambered airfoil sections with spanwise twist.** Start from relative-flow alignment, include actual swirl and required pressure in refinement, and avoid one flat pitch across the blade. The current geometric 5 m/s pitch-design value is not a measured flow prediction.
- **Broad mid-span chord and gradual tip taper.** An initial study range is roughly 28–32 mm near the working root, 30–34 mm at mid-span and 18–22 mm near the tip. Refine chord/solidity and incidence from loading, torque and separation, rather than merely scaling the old profile.
- **Moderate, smooth sweep in the outer span.** Compare unswept and moderately forward-swept planforms at matched loading. Sweep may spread interaction loading in time; its direction and magnitude need acoustic/aerodynamic comparison.
- **Rounded leading edges and a consistently finished, thinner trailing edge.** The current outer 1.2 mm trailing-edge diameter on a 14 mm tip chord is relatively blunt. Investigate thinner process-resolved edges without compromising the qualified print/strength envelope; an attractive thin CAD edge is not sufficient.
- **A removable, curved, incidence-matched stator after the motor support.** Use the present seven-vane straightener as a control article, and compare an open spacer. Streamline support struts and adjust spacing to reduce rotor-wake interaction; select the stator by net outlet speed, power and noise.
- **Rounded inlet and smooth contraction.** Keep internal seams flush and avoid abrupt steps, crowded guards and short sharp-edged slots. The nominal 1 mm radial tip gap is a fit-study starting point; actual deflection/runout determines the feasible gap.

Blade-tip leakage and rotor/stator interactions are established noise mechanisms, but the cited results do not supply a dBA prediction for Windflow. [Blade/housing tip interaction](https://mag.ebmpapst.com/en/products/fans/the-formula-for-vorticity_11766/), [NASA blade/vane-count and spacing investigation](https://ntrs.nasa.gov/citations/19850011481).

Retaining the 104 × 94 mm gross outlet with a 150/40 mm rotor gives **0.009776 / 0.016415 = 0.596** outlet-to-rotor-annulus area ratio. At the current 75% panel endpoint it is **0.447**. These ratios make the pressure requirement material. Include guards and rounded corners in the actual free-area model; give the contraction adequate length and tune its endpoint. This is why a large low-pressure propeller is insufficient and a mixed-flow comparison is valuable.

## Complete 200 mm height budget

The existing head report matches the current Rev C geometry hashes checked by this study. Across the **71 exported part groups**, the recorded installed bounds extend from **Z = −126.003 mm at the feet** to **Z = +89.848 mm at the curved linkage fairing**, a total of **215.851 mm**. This is report-derived geometry evidence, not a physical measurement or a new CAD rebuild. [Existing local bounds](../cad/rev_c/head-validation.json), [matching export part list](../cad/rev_c/integration-export-validation.json).

For the new layout, use this preliminary budget:

| Item | Vertical budget |
|---|---:|
| Rotor | 150 mm diameter |
| Throat at nominal 1 mm radial clearance | 152 mm diameter |
| Inlet with 12 mm lip radius and 2.4 mm wall | 180.8 mm outer diameter |
| Complete head, including guards and linkage kept inside its envelope | 185 mm |
| Base and feet extending below that head | 10 mm |
| **Target complete product height** | **195 mm** |
| Reserve to user's maximum | **5 mm** |

The 10 mm extension is a structural plinth/feet budget, **not** the height available for all electronics. Place the screen and encoder in the front lower portion of the head, below the smaller outlet. The existing screen bezel is about 39.6 mm high: a centered 94 mm outlet in a 185 mm head leaves 45.5 mm below it, approximately enough for that bezel plus a 5 mm gap. Reserve more space where fasteners, lenses and cable access need it.

Place the controller and other electronics in downstream lower/side pockets **outside the air duct**. Use width/depth rather than adding height; preserve the visible screen status band, encoder orientation, service access and independent electronics cooling. Reposition the linkage so its fairing stays inside the head budget. This needs revised CAD and assembly clearance verification; the arithmetic alone does not demonstrate fit or manufacturability.

## Make boost visibly useful without sacrificing normal quietness

The current control maps normal maximum and boost to the **same maximum rotor speed**, with boost closing the outlet. Thus boost presently relies entirely on sufficient flow retention during contraction. Preserve the full fresh encoder turn to arm boost and the progressive control afterwards.

For the current 75% area endpoint, at the **same RPM**:

| Boost flow / normal flow | Boost velocity / normal velocity | Change |
|---|---:|---:|
| 100% | 1.333× | +33.3% |
| 95% | 1.267× | +26.7% |
| 90% | 1.200× | +20.0% |
| 85% | 1.133× | +13.3% |
| 80% | 1.067× | +6.7% |
| 75% | 1.000× | No increase |
| 70% | 0.933× | −6.7% |

A **20% measured speed increase requires at least 90% flow retention** at 75% area. A 25% increase requires at least 93.75%. Smaller area alone cannot guarantee the requested effect.

The recommended control development is to reserve roughly **15–20% of qualified maximum RPM** above normal maximum, then combine that RPM reserve with the measured beneficial panel travel. As a starting mapping, normal maximum could be 80% of qualified boost RPM, with the outlet open. For a similar stage at the same outlet, its aerodynamic power component would be about **0.8³ = 51.2%** of the boost-speed component, leaving meaningful power headroom. Do not equate this to a guaranteed 9.2 W electrical normal setting: fixed losses, efficiency and nozzle position change the operating point.

During boost arming, hold normal maximum and open panels, as the current interaction requires. After arming, smoothly coordinate RPM and closure from a measured map. Target **at least 20% and preferably 25–30% higher area-average outlet velocity** than normal maximum, with a useful increase at 0.5 m. These are acceptance targets, not predicted outputs. Select the quietest map that satisfies them. If closure reduces flow or adds hiss without enough speed benefit, use less closure and more of the qualified RPM reserve.

Retain the 18 W input limit and qualified current, RPM and thermal limits. The current 18/24 Pa pressure settings are unqualified restriction-monitor values; they are not a fan curve or necessarily total fan pressure. Map them to actual tap measurements before tuning. They may prevent an effective boost if the chosen stage's measured pressures exceed them, but simply increasing them cannot establish a safe operating point.

## What is and is not numerically established

No trustworthy absolute m/s or dBA prediction is available without a fan curve, motor loss map and acoustic measurements. As an energy check only, a uniform ambient-pressure jet has `Pjet = 0.5 ρ A V³`. With rho = 1.2 kg/m³ and the current gross areas, putting **all 18 W input** into jet kinetic energy gives ideal ceilings of about **14.5 m/s open** and **16.0 m/s at 75% area**. These are unattainable loss-free ceilings, not performance estimates.

Using the generous 3 A / 3,000 RPM electromagnetic estimate of 4.37 W instead gives corresponding ideal ceilings of about **9.1 and 10.0 m/s**, before motor friction, rotor/stator loss, swirl and guard/nozzle losses. Actual output must be below the applicable energy ceiling, and the Kt/current convention must first be resolved. These checks reinforce that the phase-current limit materially affects the airspeed target.

## Comparison needed to select the final shape

Compare the existing 112 mm P1, 150 mm five-blade axial, 150 mm seven-blade axial with similar total solidity, and a mild mixed-flow candidate. Include a 125–140 mm comparator if torque remains constrained. Establish the actual motor/rotor operating envelope before taking performance data; the existing printed rotor's development status cannot qualify a larger replacement.

For each complete stage, record RPM, phase/input current, input power, temperatures, outlet velocity traverse/flow, pressure, velocity at 0.5/1 m, sound and vibration over open and progressively contracted positions. Test the stator and open-spacer variants at equal useful output. Rank the stages by maximum useful mean airspeed within the 200 mm envelope and qualified limits, then choose the lowest-noise normal operating point that retains the required boost increment.

The present evidence supports the **150 mm swept/twisted five-blade axial stage as the first development choice**, with the mixed-flow stage as a serious pressure-focused comparator. It does not support declaring any untested shape the fastest or assigning it a sound level.

Reproducible results: [calculation record](fan-shape-study-2026-10-09/calculations.json), [diameter comparison](fan-shape-study-2026-10-09/diameter-scaling.csv), [boost continuity calculation](fan-shape-study-2026-10-09/boost-retention.csv), [motor matching estimates](fan-shape-study-2026-10-09/motor-power-estimates.csv). Generated by [the study calculation](../tools/analyse_fan_shapes.py).

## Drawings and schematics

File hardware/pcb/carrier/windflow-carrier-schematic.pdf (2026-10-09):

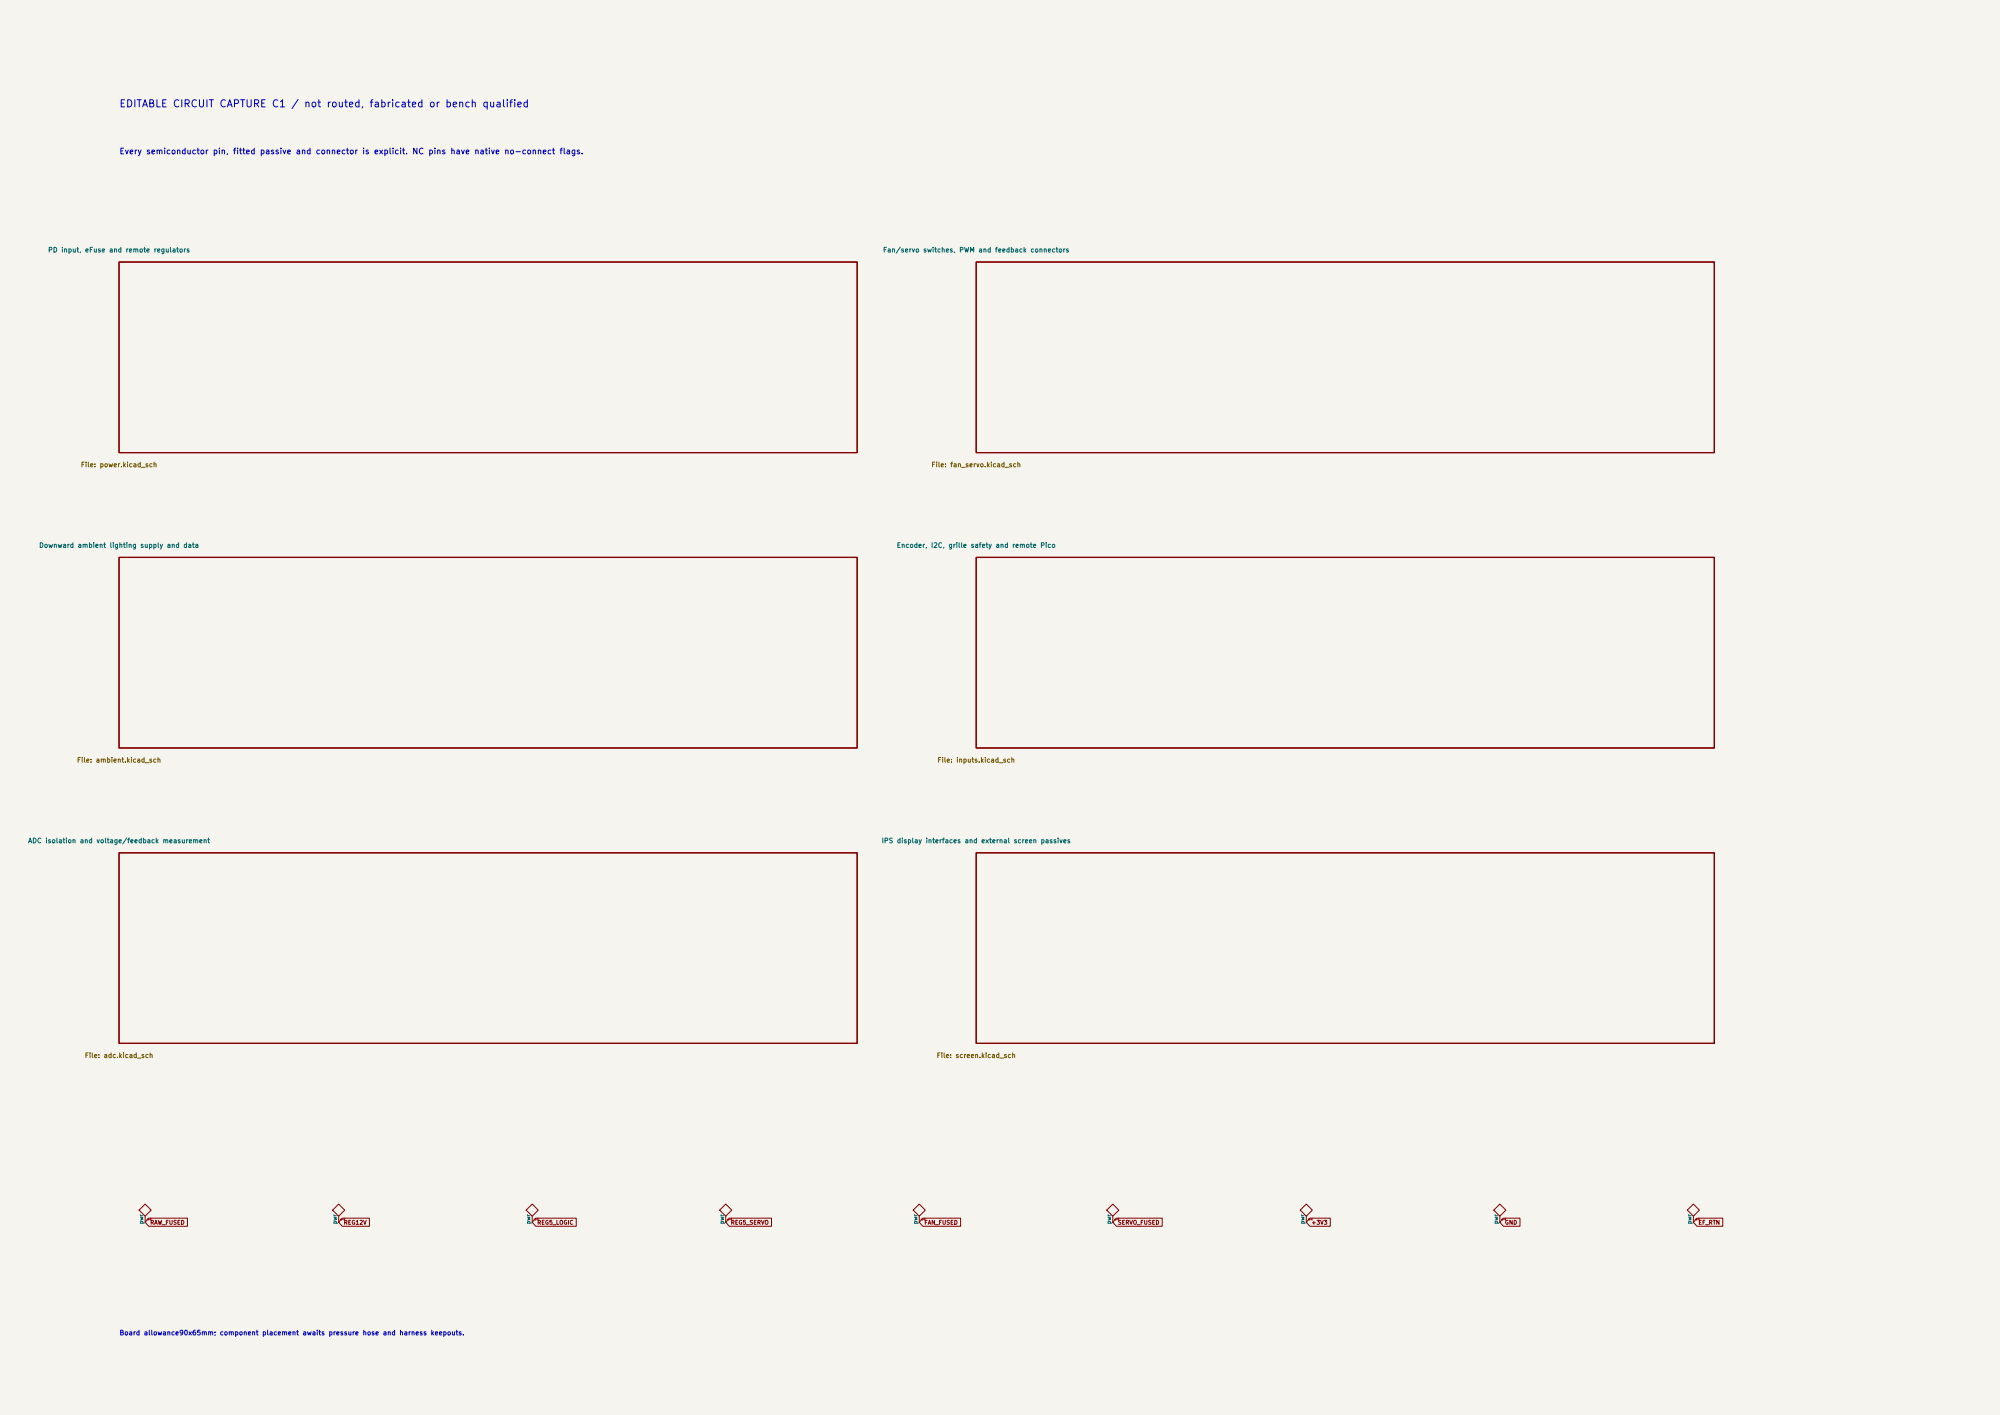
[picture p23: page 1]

EDITABLE CIRCUIT CAPTURE C1 / not routed, fabricated or bench qualified

Every semiconductor pin, fitted passive and connector is explicit. NC pins have native no-connect flags.

PD input, eFuse and remote regulators File: power.kicad_sch Downward ambient lighting supply and data

Fan/servo switches, PWM and feedback connectors File: fan_servo.kicad_sch

Encoder, I2C, grille safety and remote Pico

IPS display interfaces and external screen passives File: screen.kicad_sch

Board allowance90x65mm; component placement awaits pressure hose and harness keepouts.

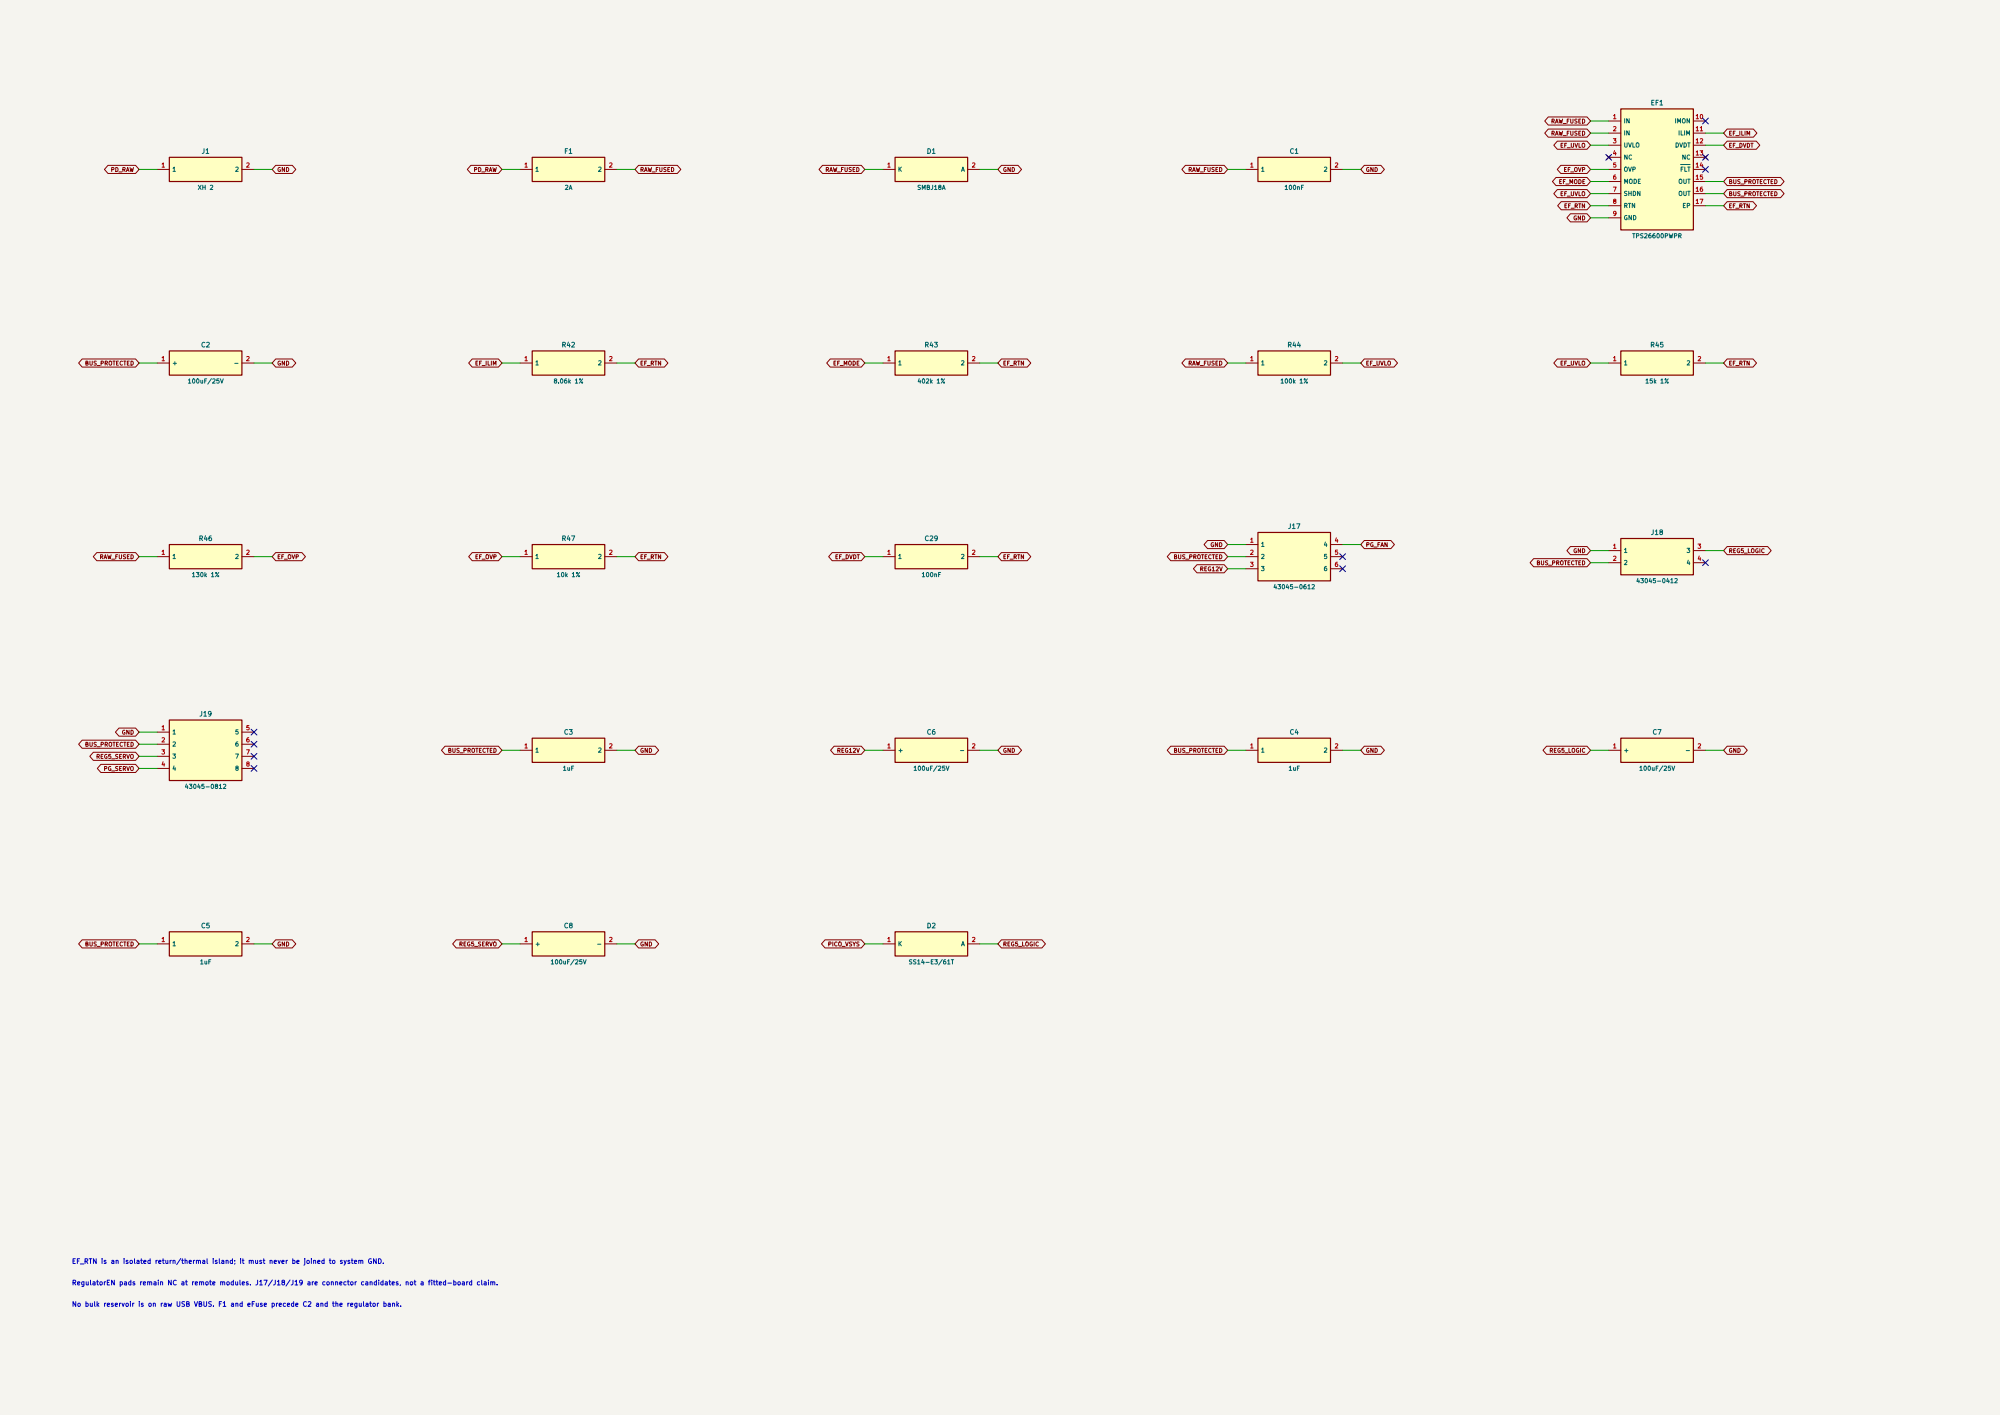
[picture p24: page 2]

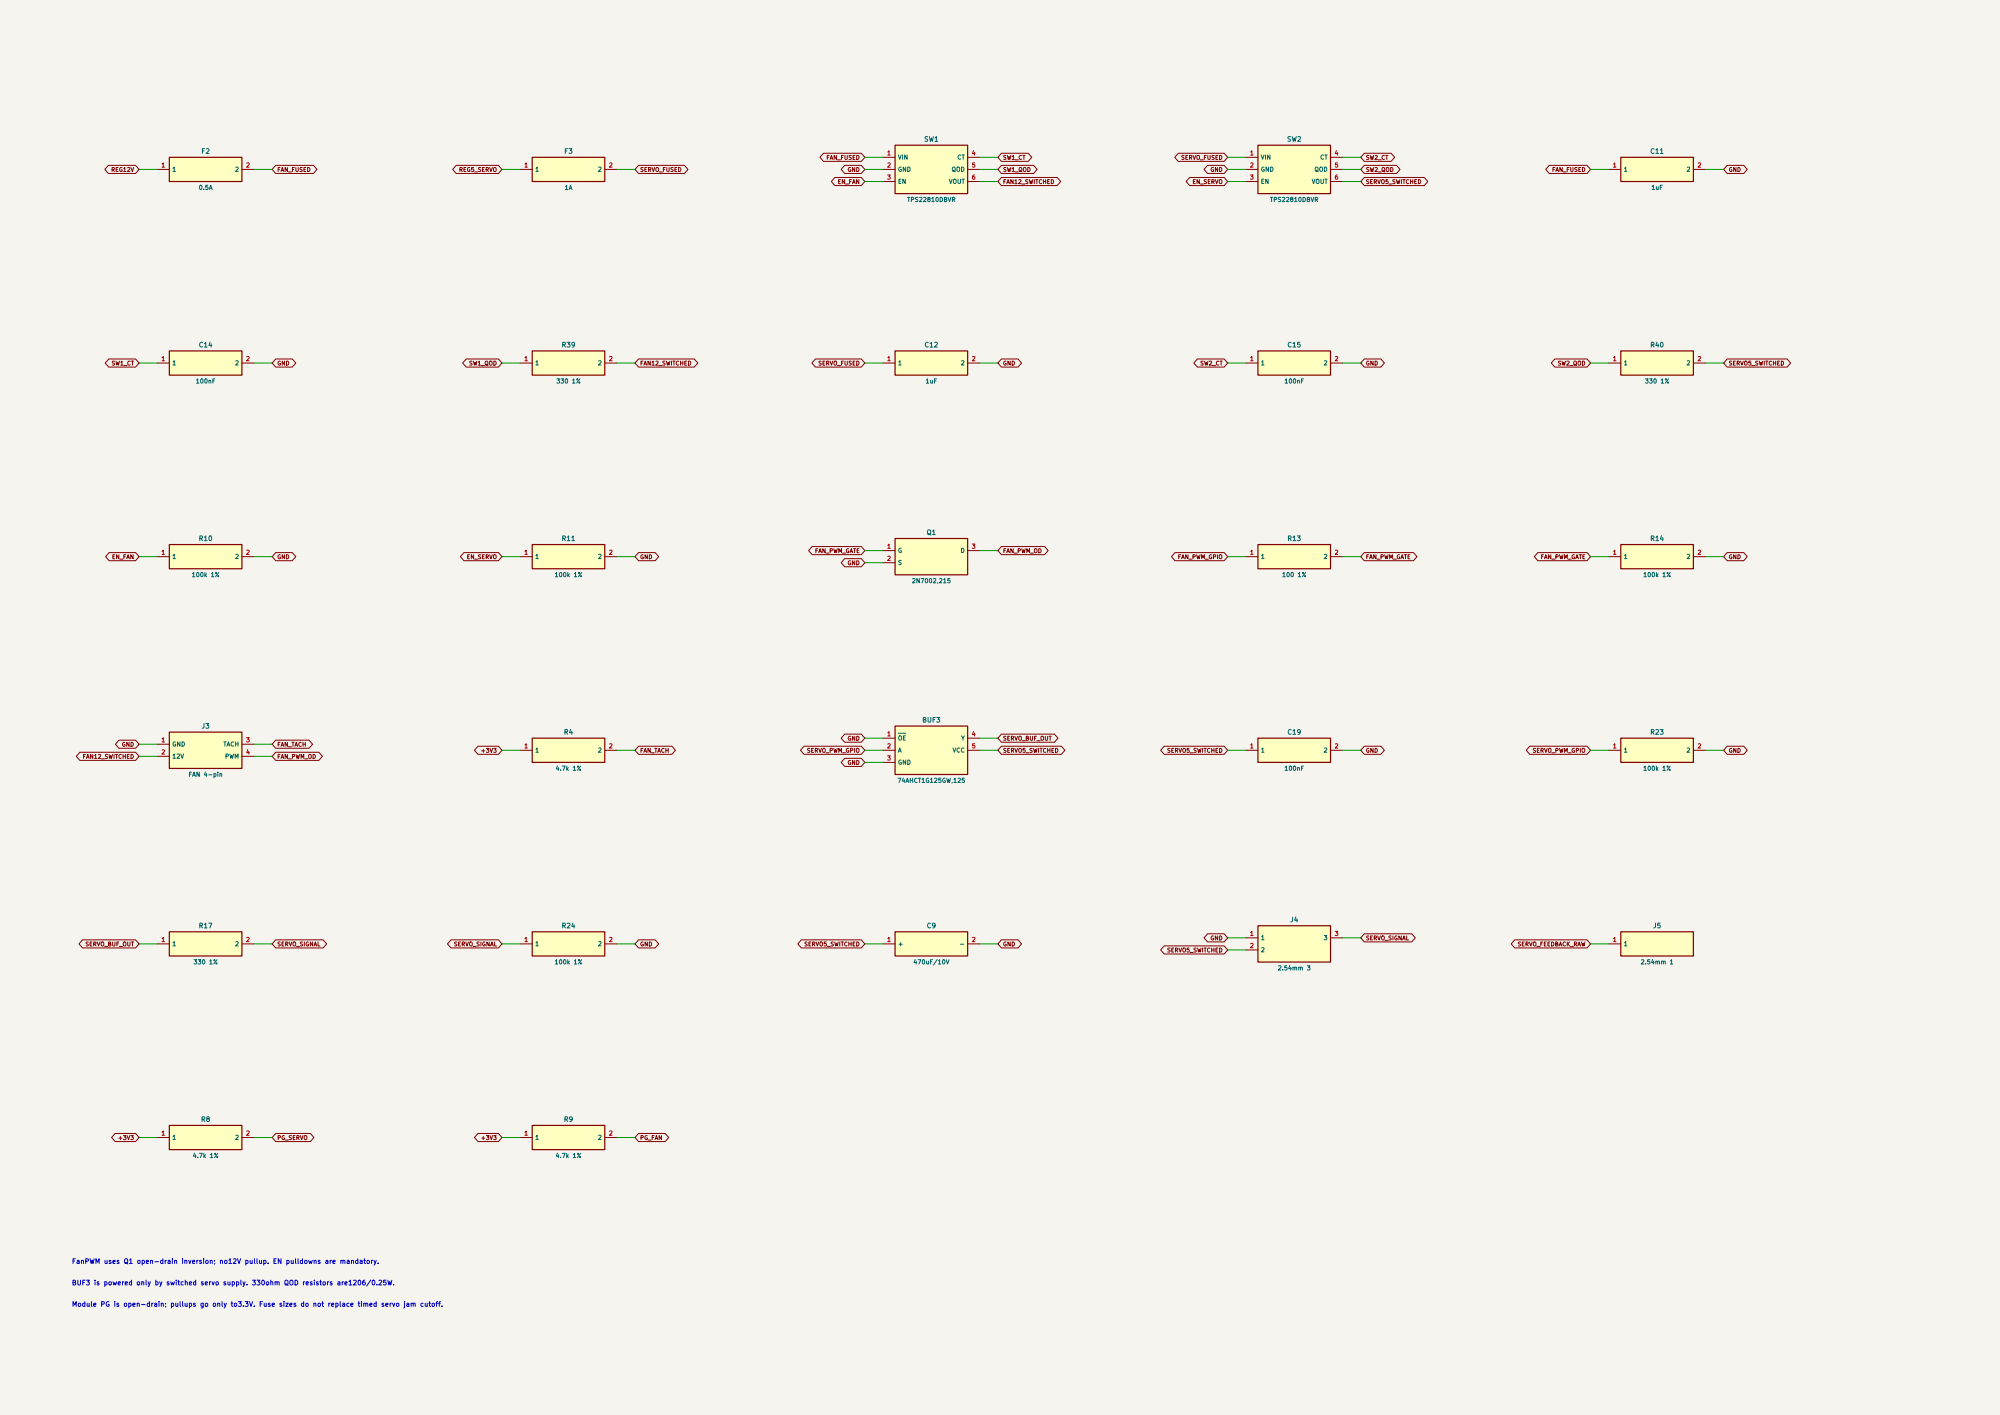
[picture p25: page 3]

FanPWM uses Q1 open-drain inversion; no12V pullup. EN pulldowns are mandatory. BUF3 is powered only by switched servo supply. 330ohm QOD resistors are1206/0.25W. Module PG is open-drain; pullups go only to3.3V. Fuse sizes do not replace timed servo jam cutoff.

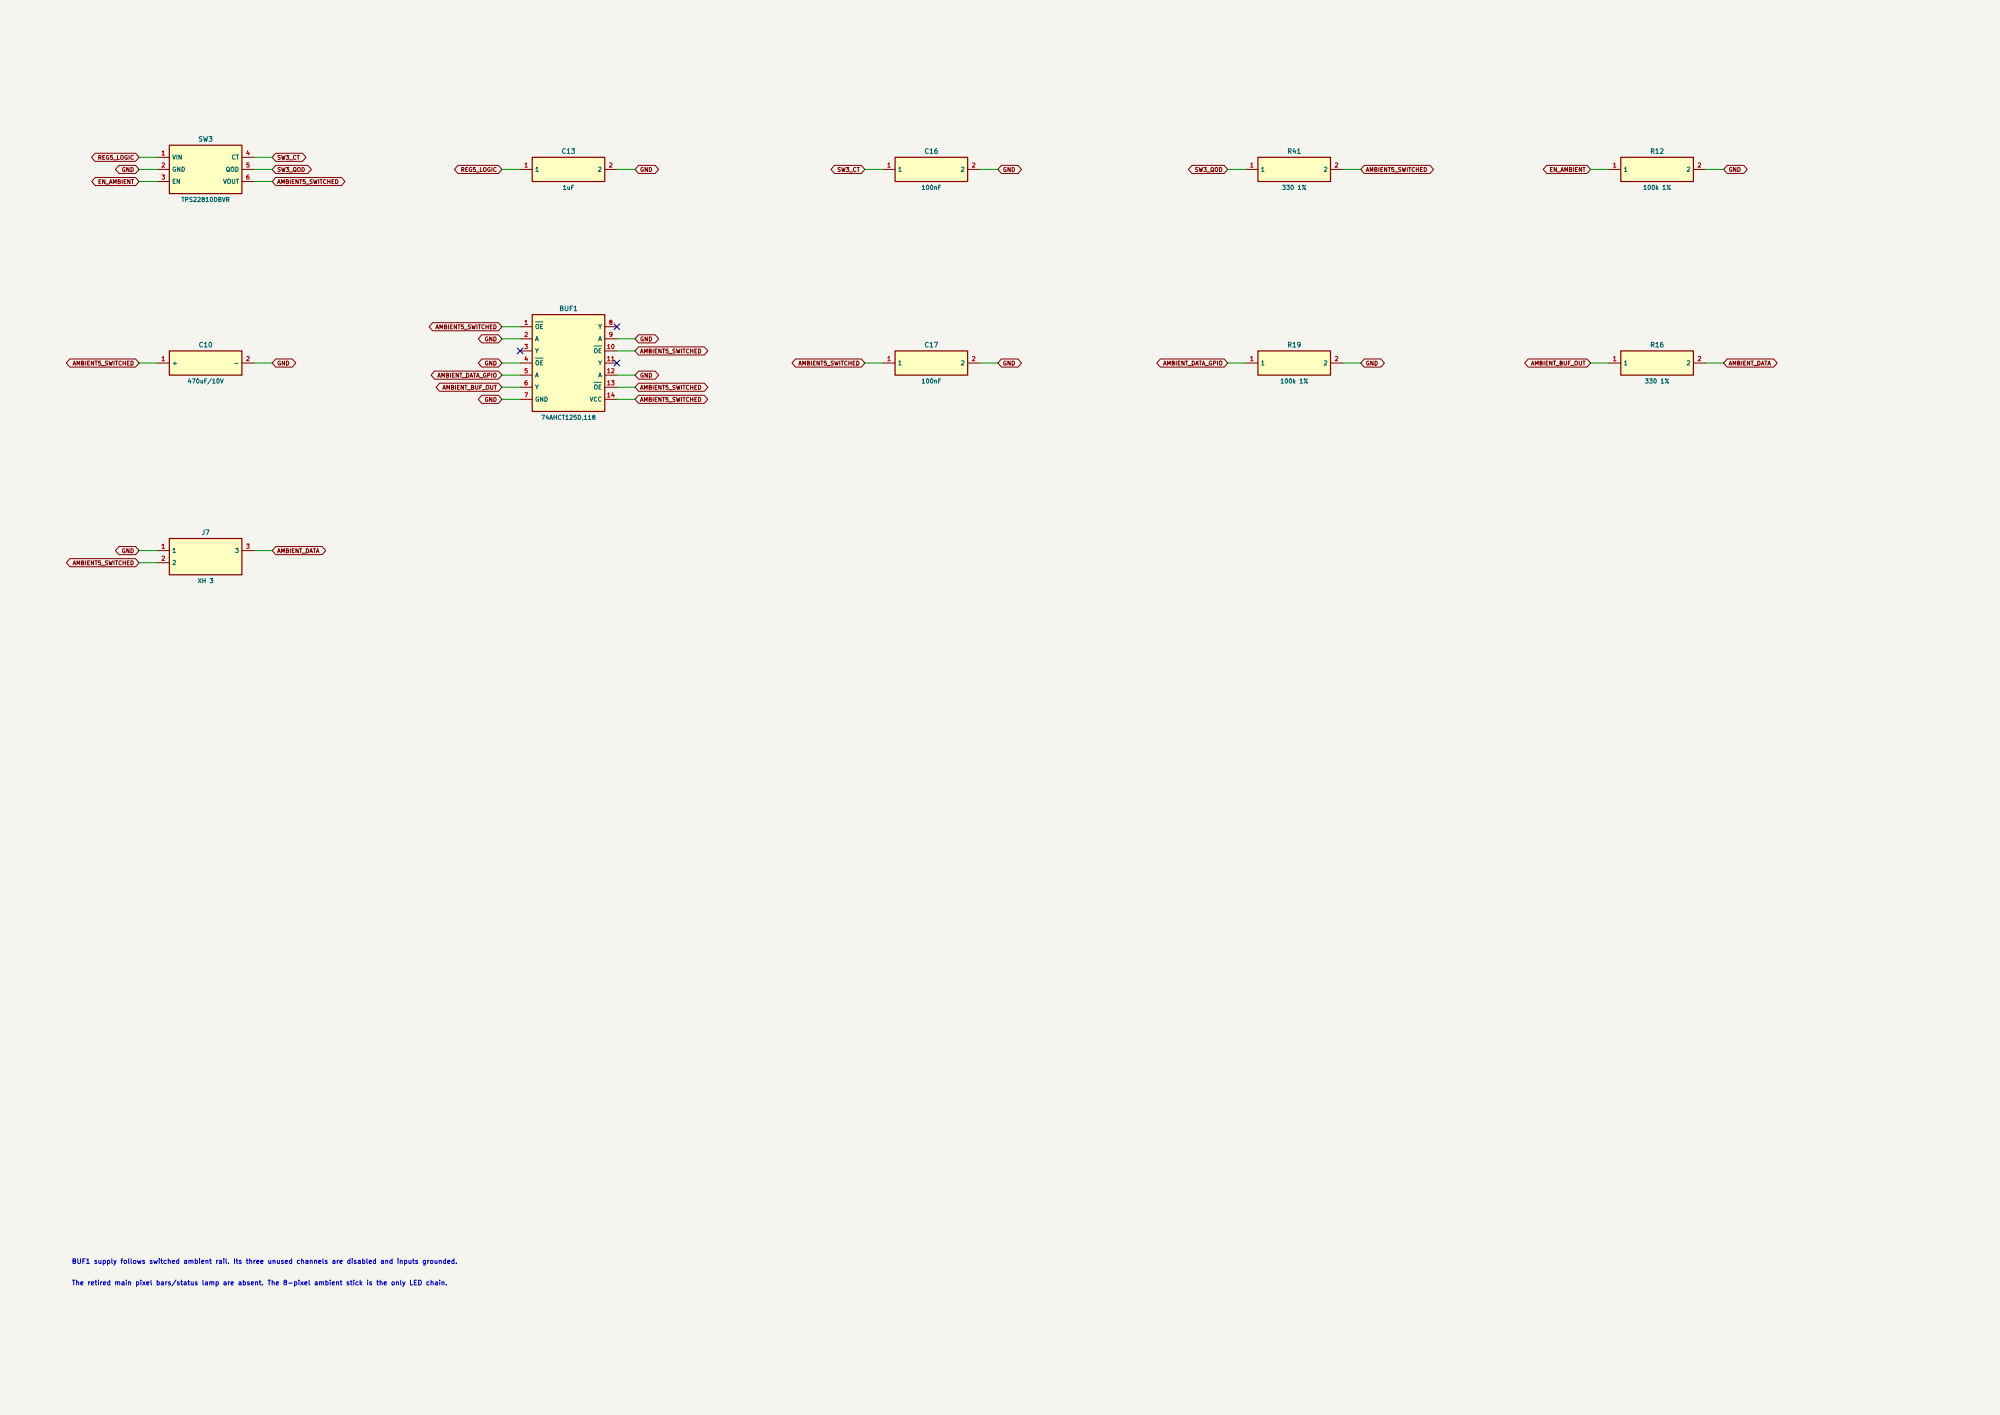
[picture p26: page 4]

BUF1 supply follows switched ambient rail. Its three unused channels are disabled and inputs grounded. The retired main pixel bars/status lamp are absent. The 8-pixel ambient stick is the only LED chain.

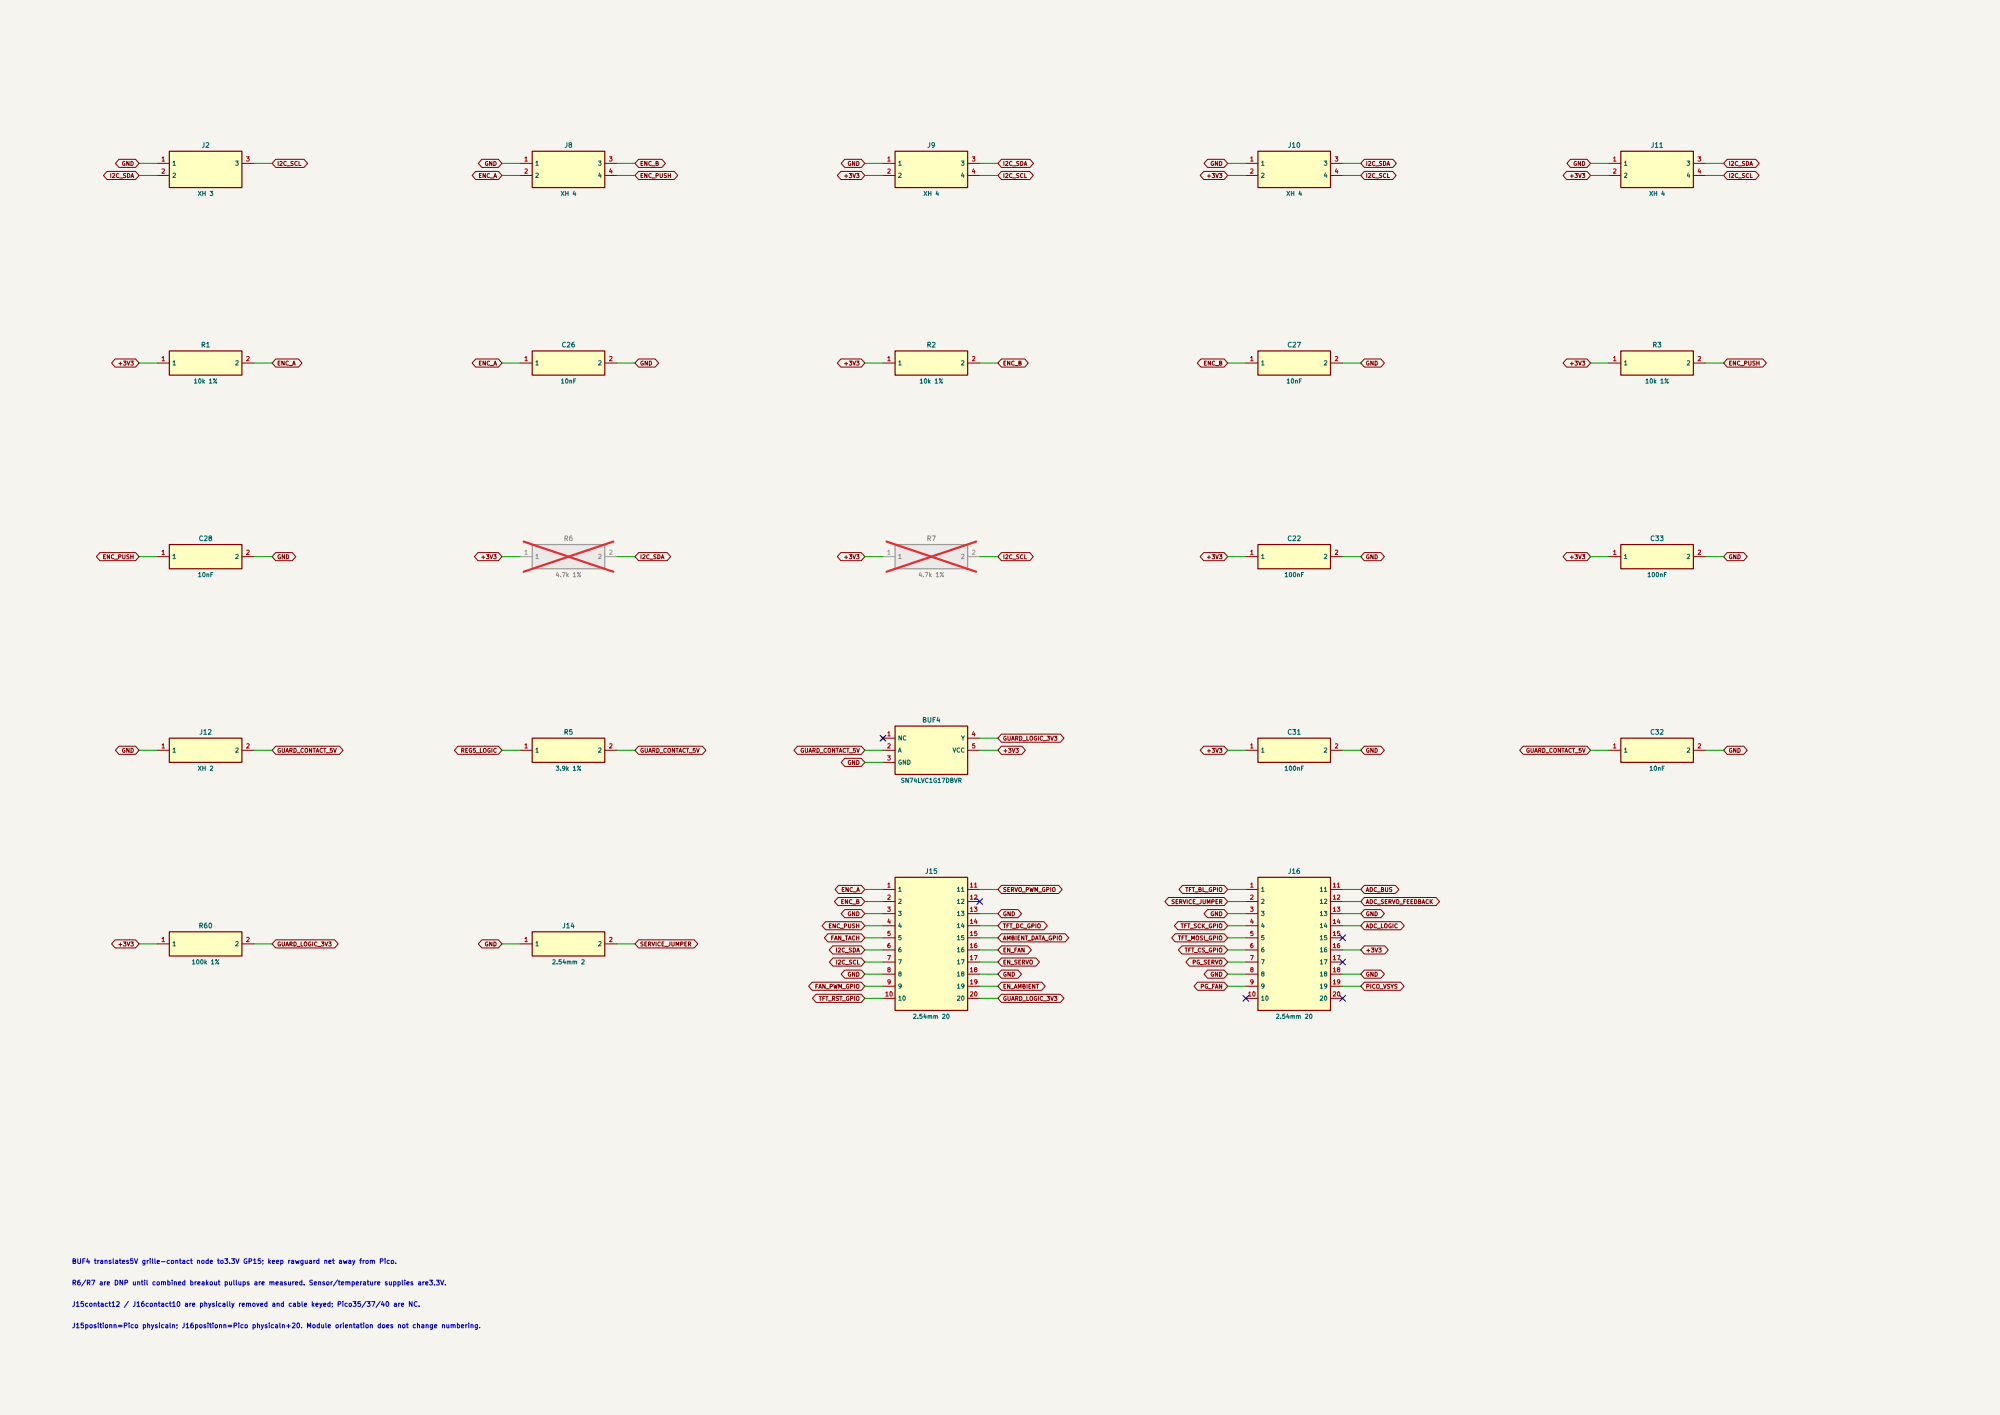
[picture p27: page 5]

BUF4 translates5V grille-contact node to3.3V GP15; keep rawguard net away from Pico. J15contact12 / J16contact10 are physically removed and cable keyed; Pico35/37/40 are NC. J15positionn=Pico physicaln; J16positionn=Pico physicaln+20. Module orientation does not change numbering. R6/R7 are DNP until combined breakout pullups are measured. Sensor/temperature supplies are3.3V.

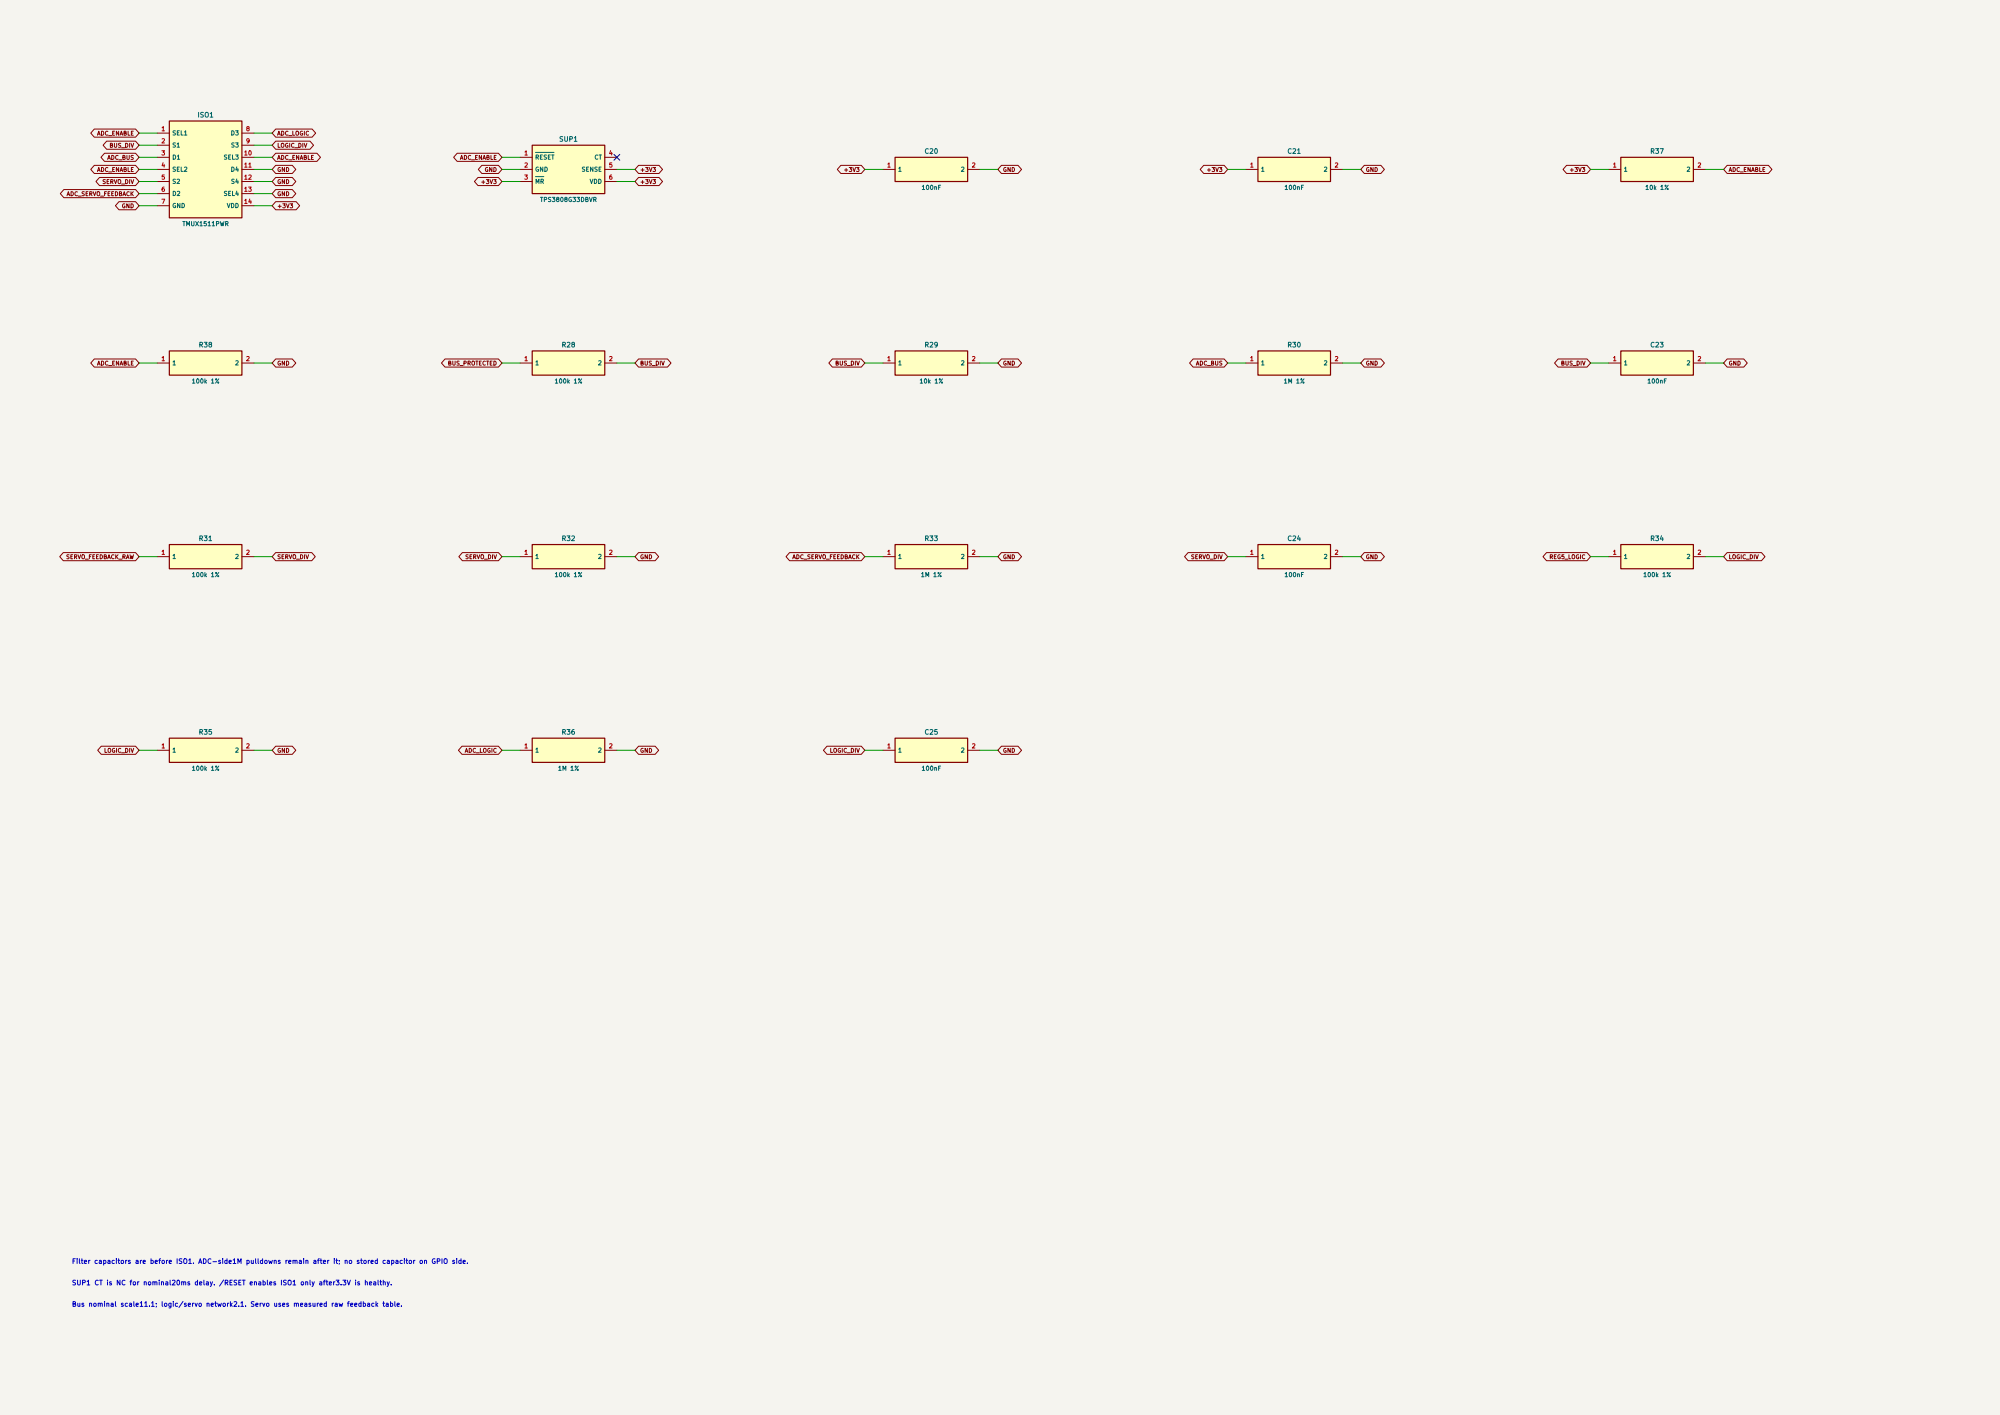
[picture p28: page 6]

SUP1 CT is NC for nominal20ms delay. /RESET enables ISO1 only after3.3V is healthy. Filter capacitors are before ISO1. ADC-side1M pulldowns remain after it; no stored capacitor on GPIO side. Bus nominal scale11.1; logic/servo network2.1. Servo uses measured raw feedback table.

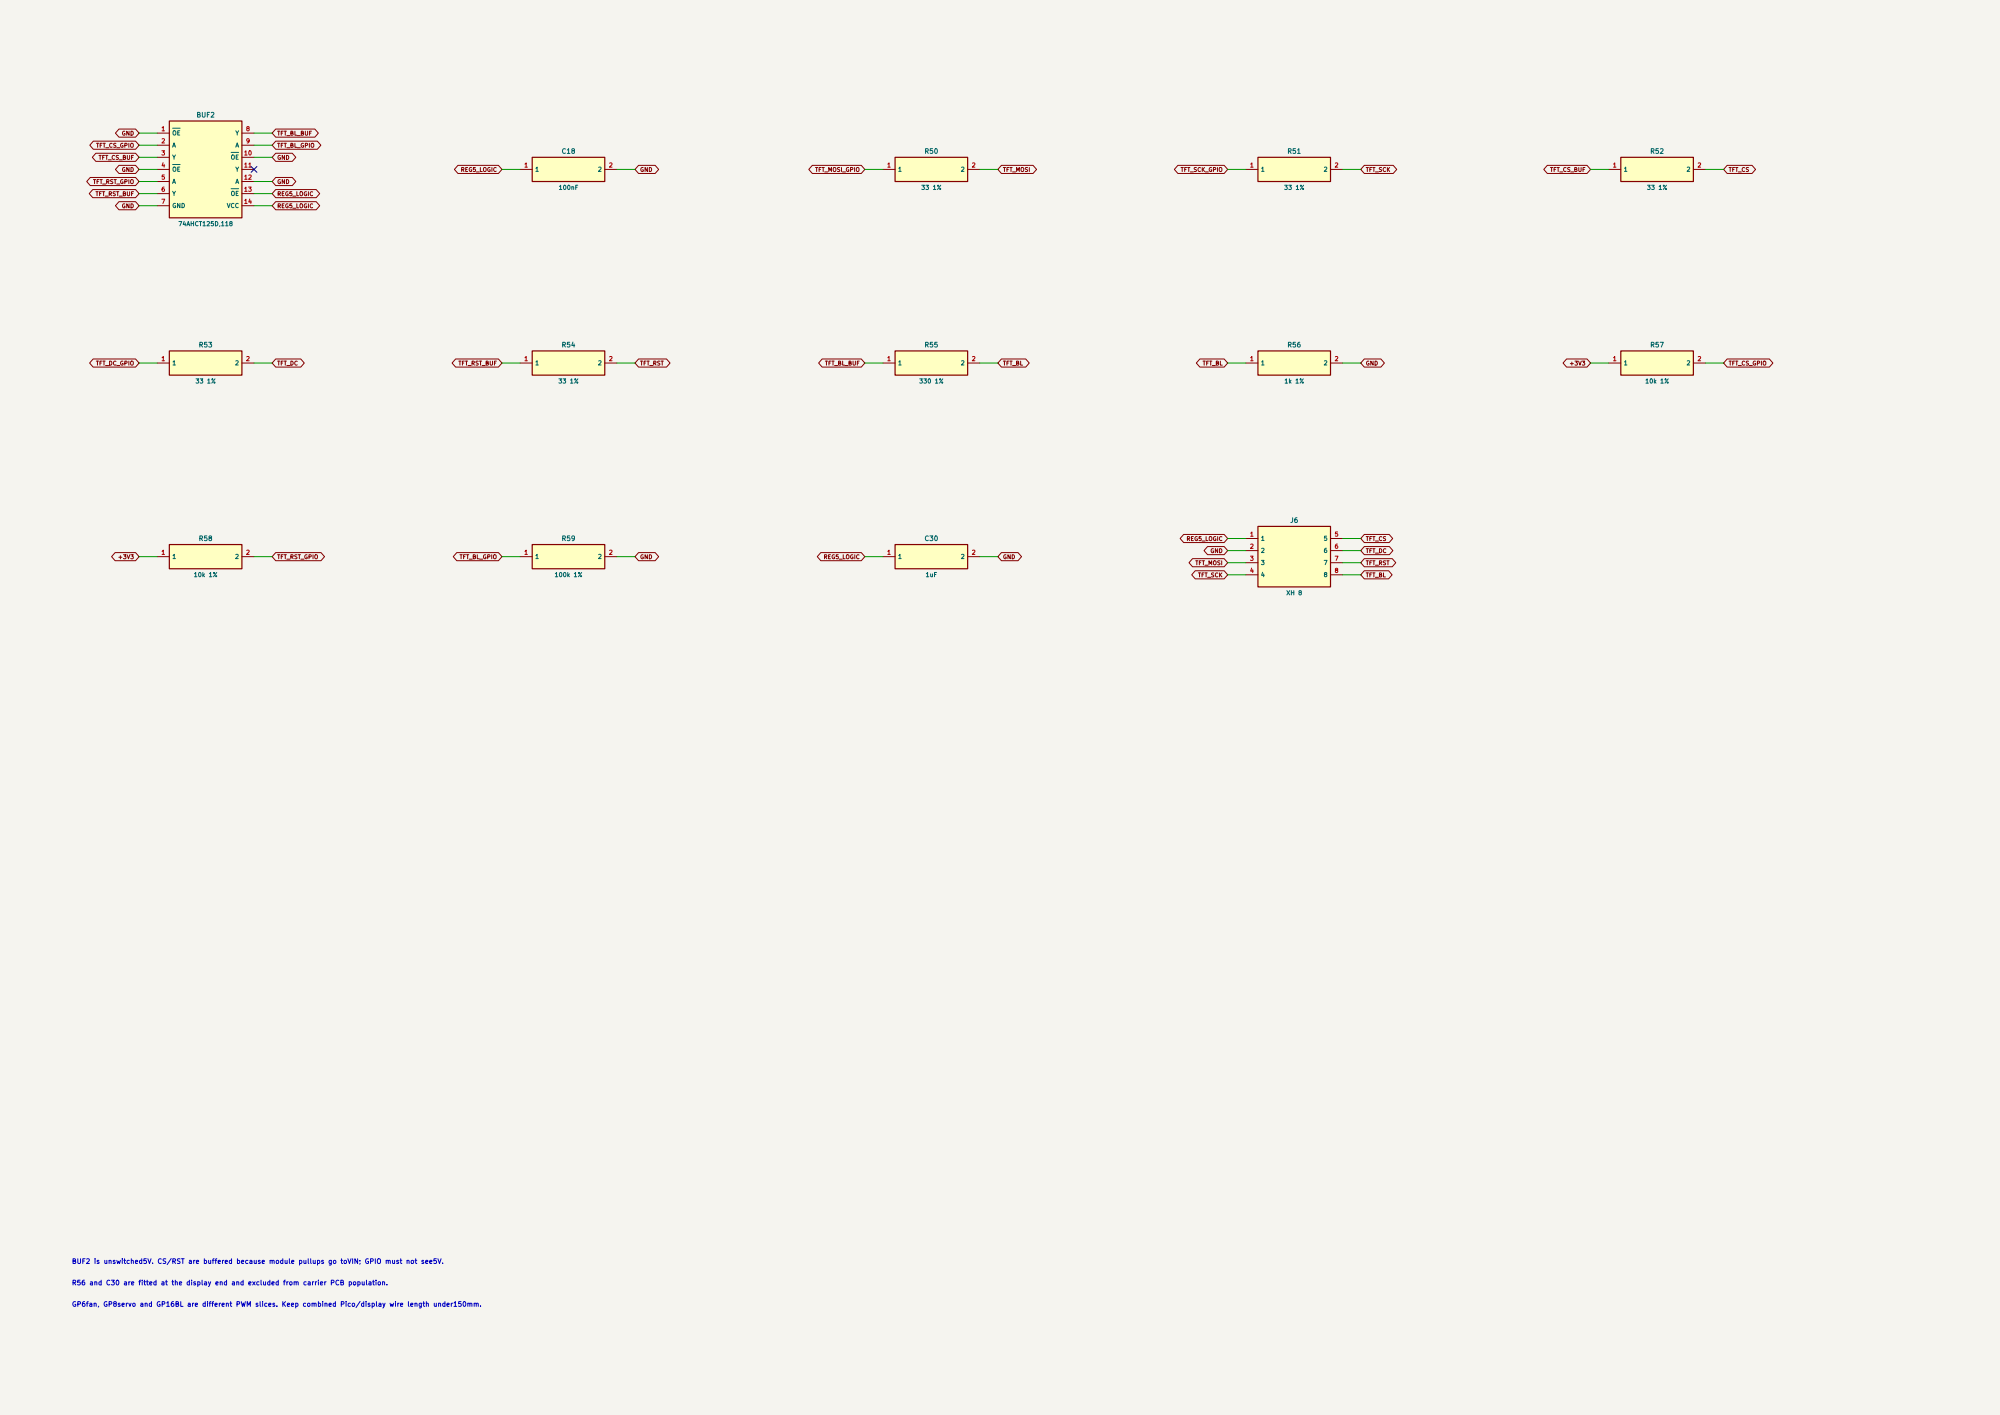
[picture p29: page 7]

BUF2 is unswitched5V. CS/RST are buffered because module pullups go toVIN; GPIO must not see5V. R56 and C30 are fitted at the display end and excluded from carrier PCB population. GP6fan, GP8servo and GP16BL are different PWM slices. Keep combined Pico/display wire length under150mm.

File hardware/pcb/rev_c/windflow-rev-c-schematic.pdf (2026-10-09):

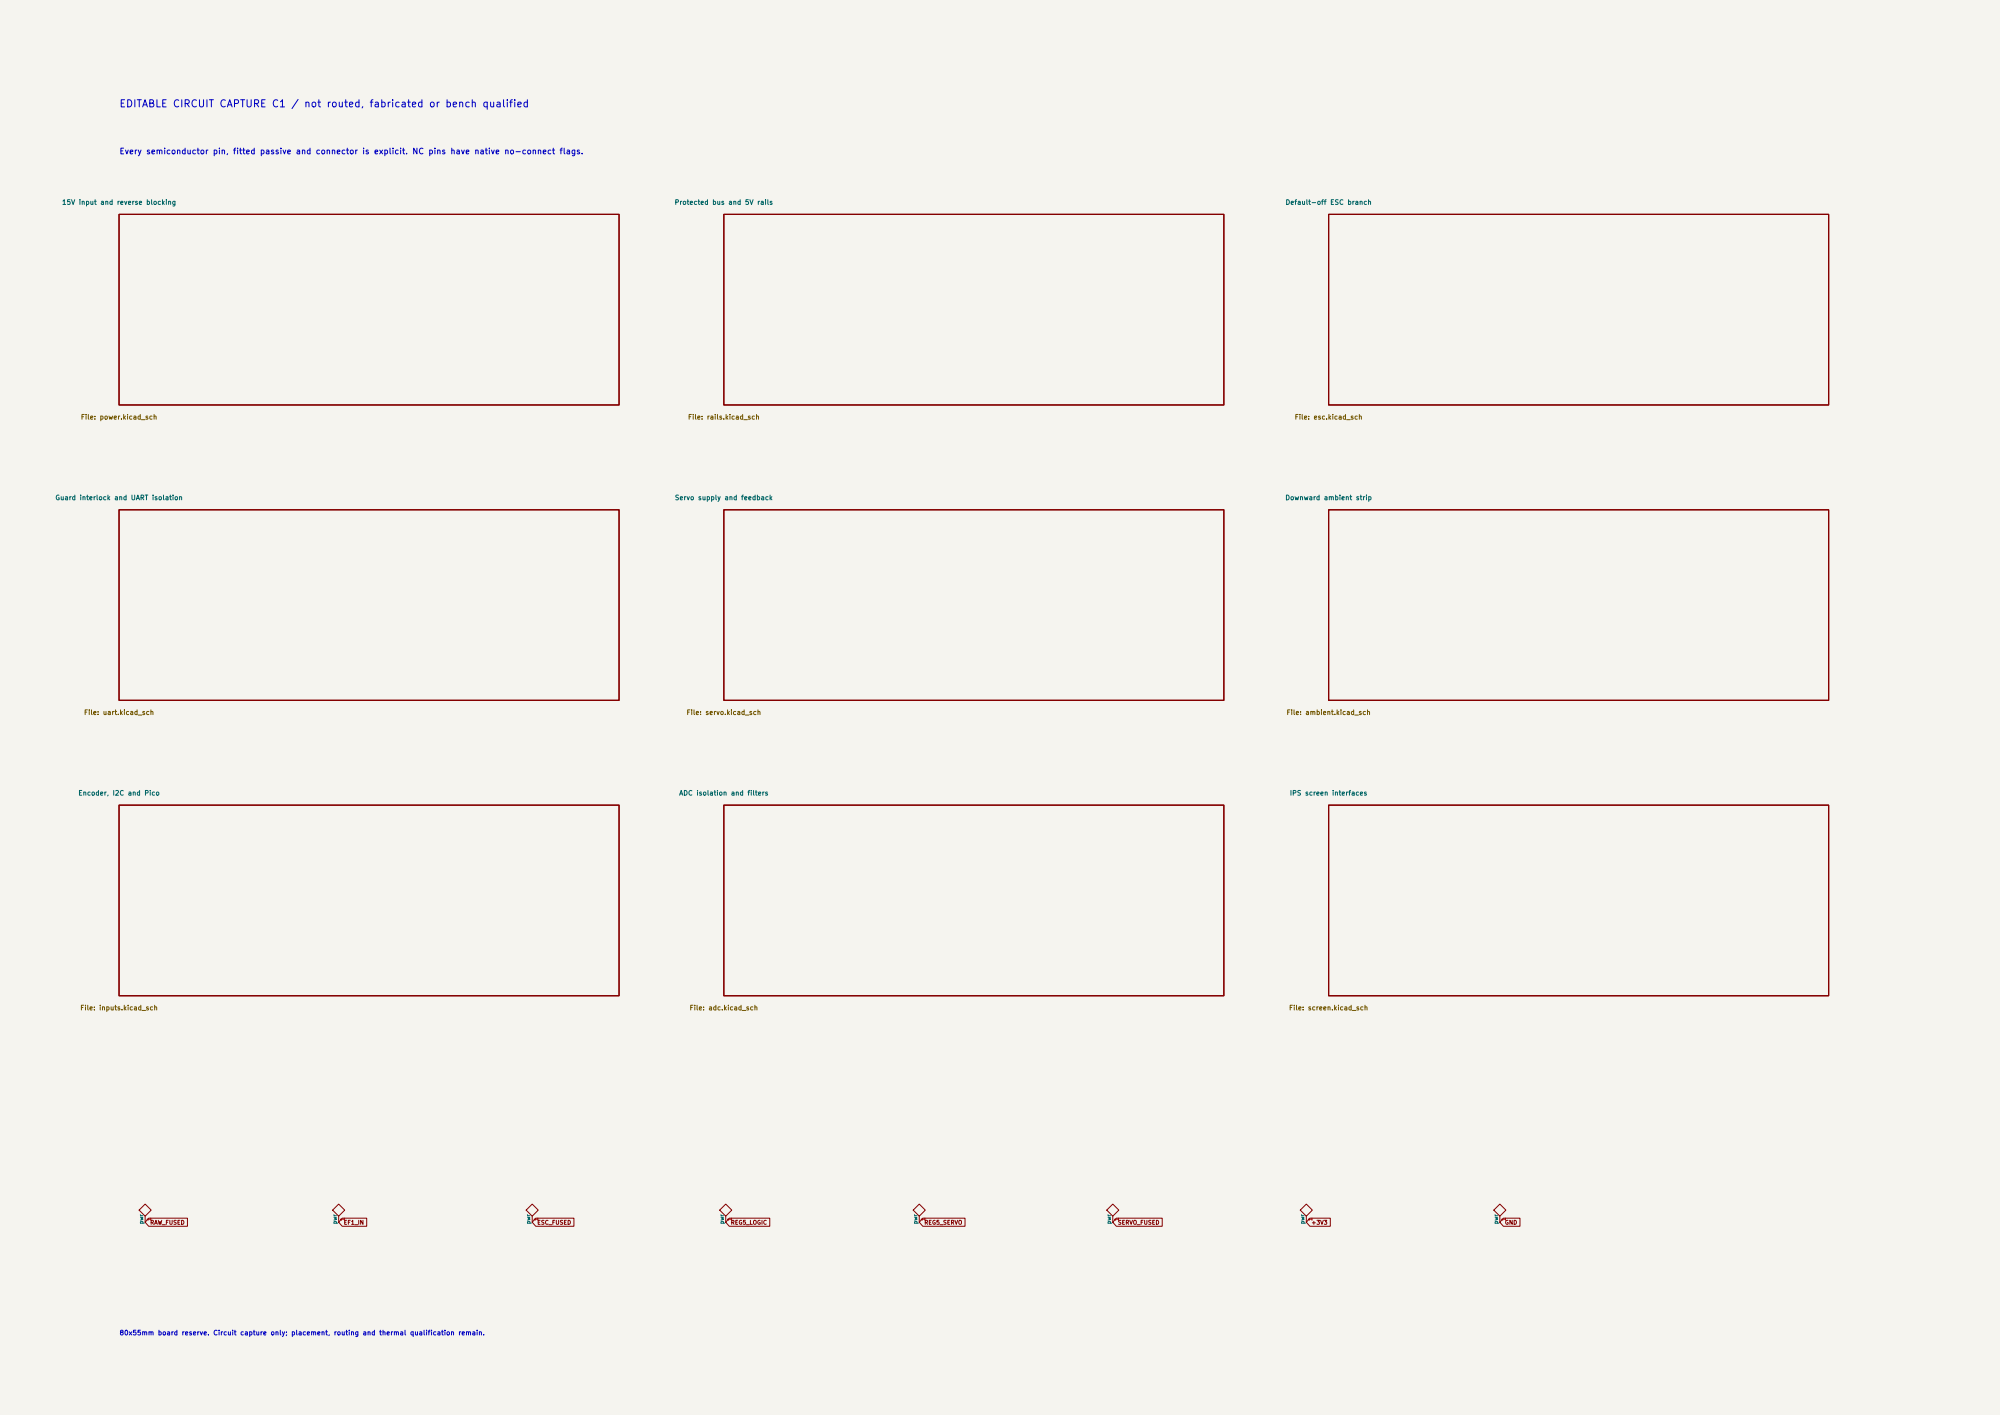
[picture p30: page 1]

EDITABLE CIRCUIT CAPTURE C1 / not routed, fabricated or bench qualified

Every semiconductor pin, fitted passive and connector is explicit. NC pins have native no-connect flags.

15V input and reverse blocking

Default-off ESC branch

File: ambient.kicad_sch
IPS screen interfaces File: screen.kicad_sch

ADC isolation and filters File: adc.kicad_sch

80x55mm board reserve. Circuit capture only; placement, routing and thermal qualification remain.

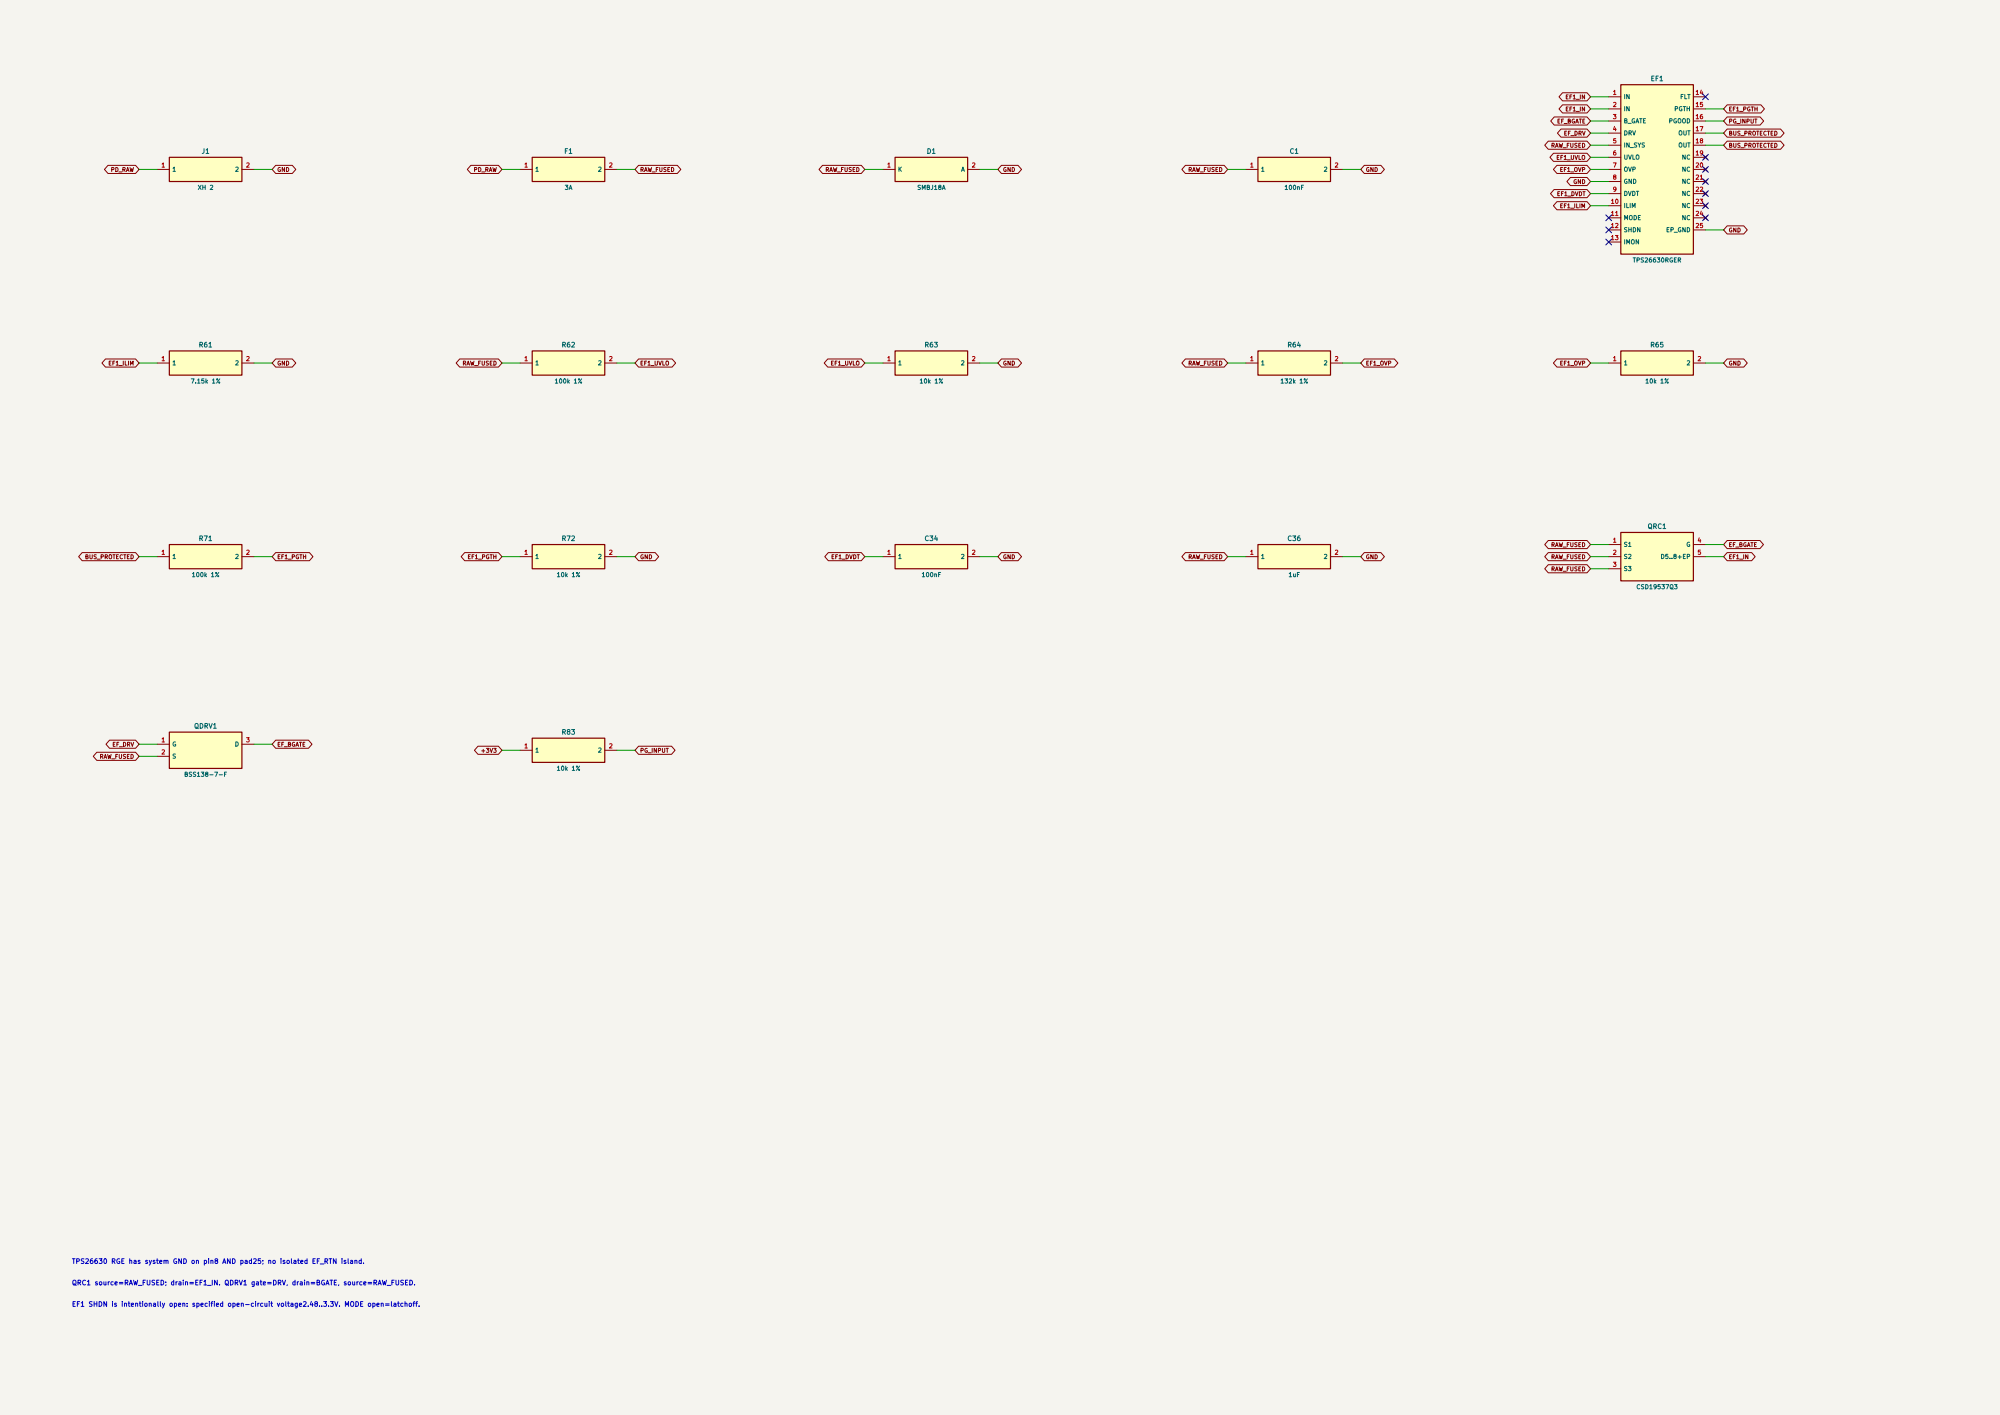
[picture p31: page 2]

TPS26630 RGE has system GND on pin8 AND pad25; no isolated EF_RTN island. QRC1 source=RAW_FUSED; drain=EF1_IN. QDRV1 gate=DRV, drain=BGATE, source=RAW_FUSED. EF1 SHDN is intentionally open: specified open-circuit voltage2.48..3.3V. MODE open=latchoff.

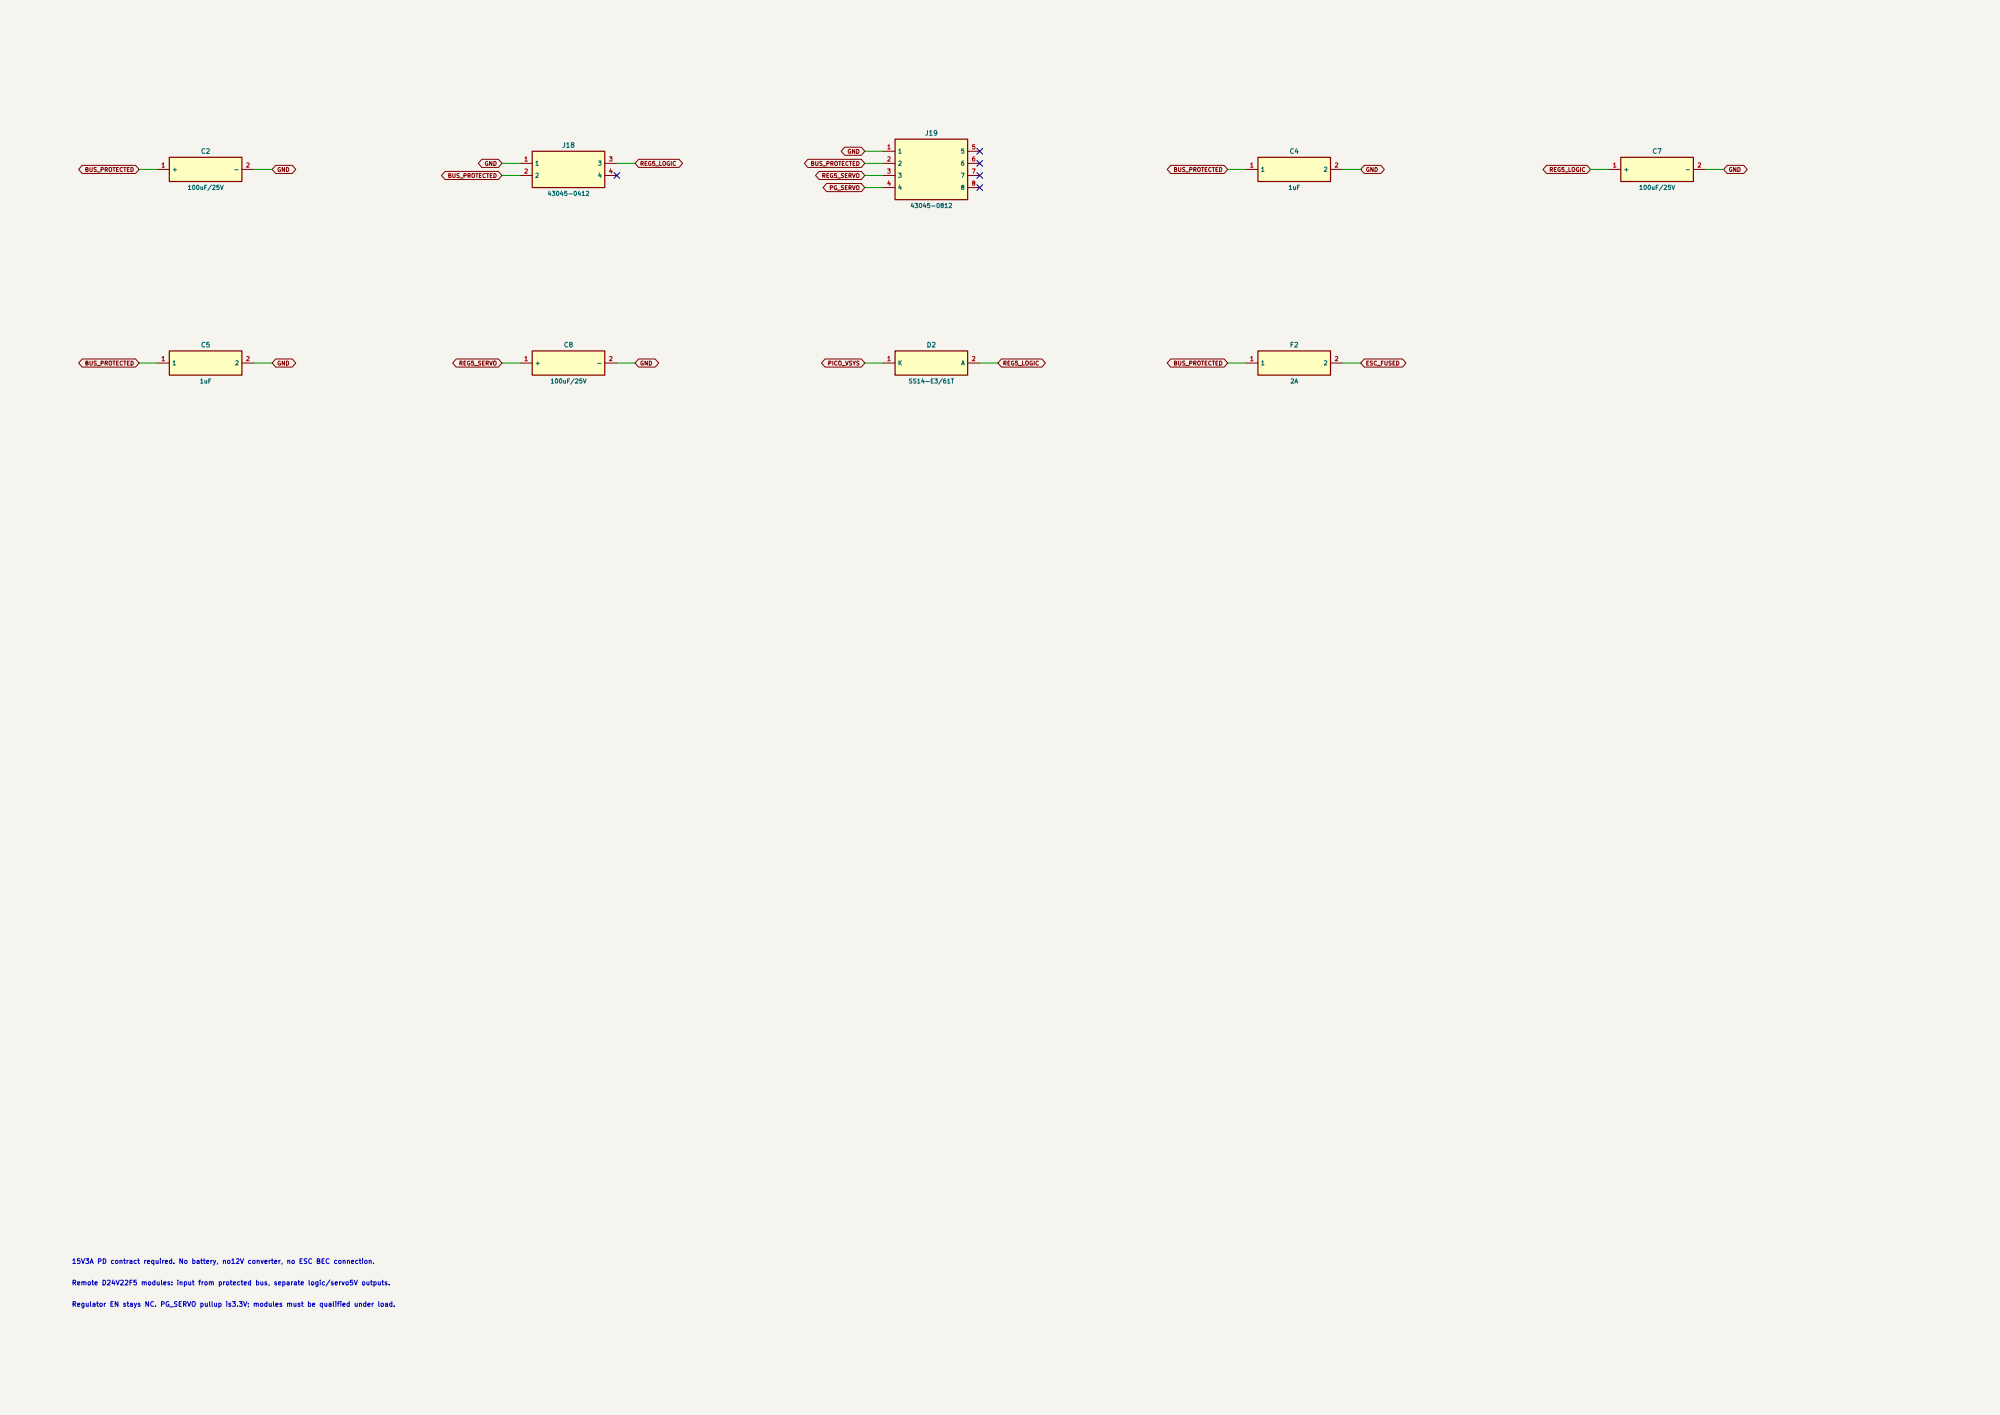
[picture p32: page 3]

Regulator EN stays NC. PG_SERVO pullup is3.3V; modules must be qualified under load. 15V3A PD contract required. No battery, no12V converter, no ESC BEC connection. Remote D24V22F5 modules: input from protected bus, separate logic/servo5V outputs.

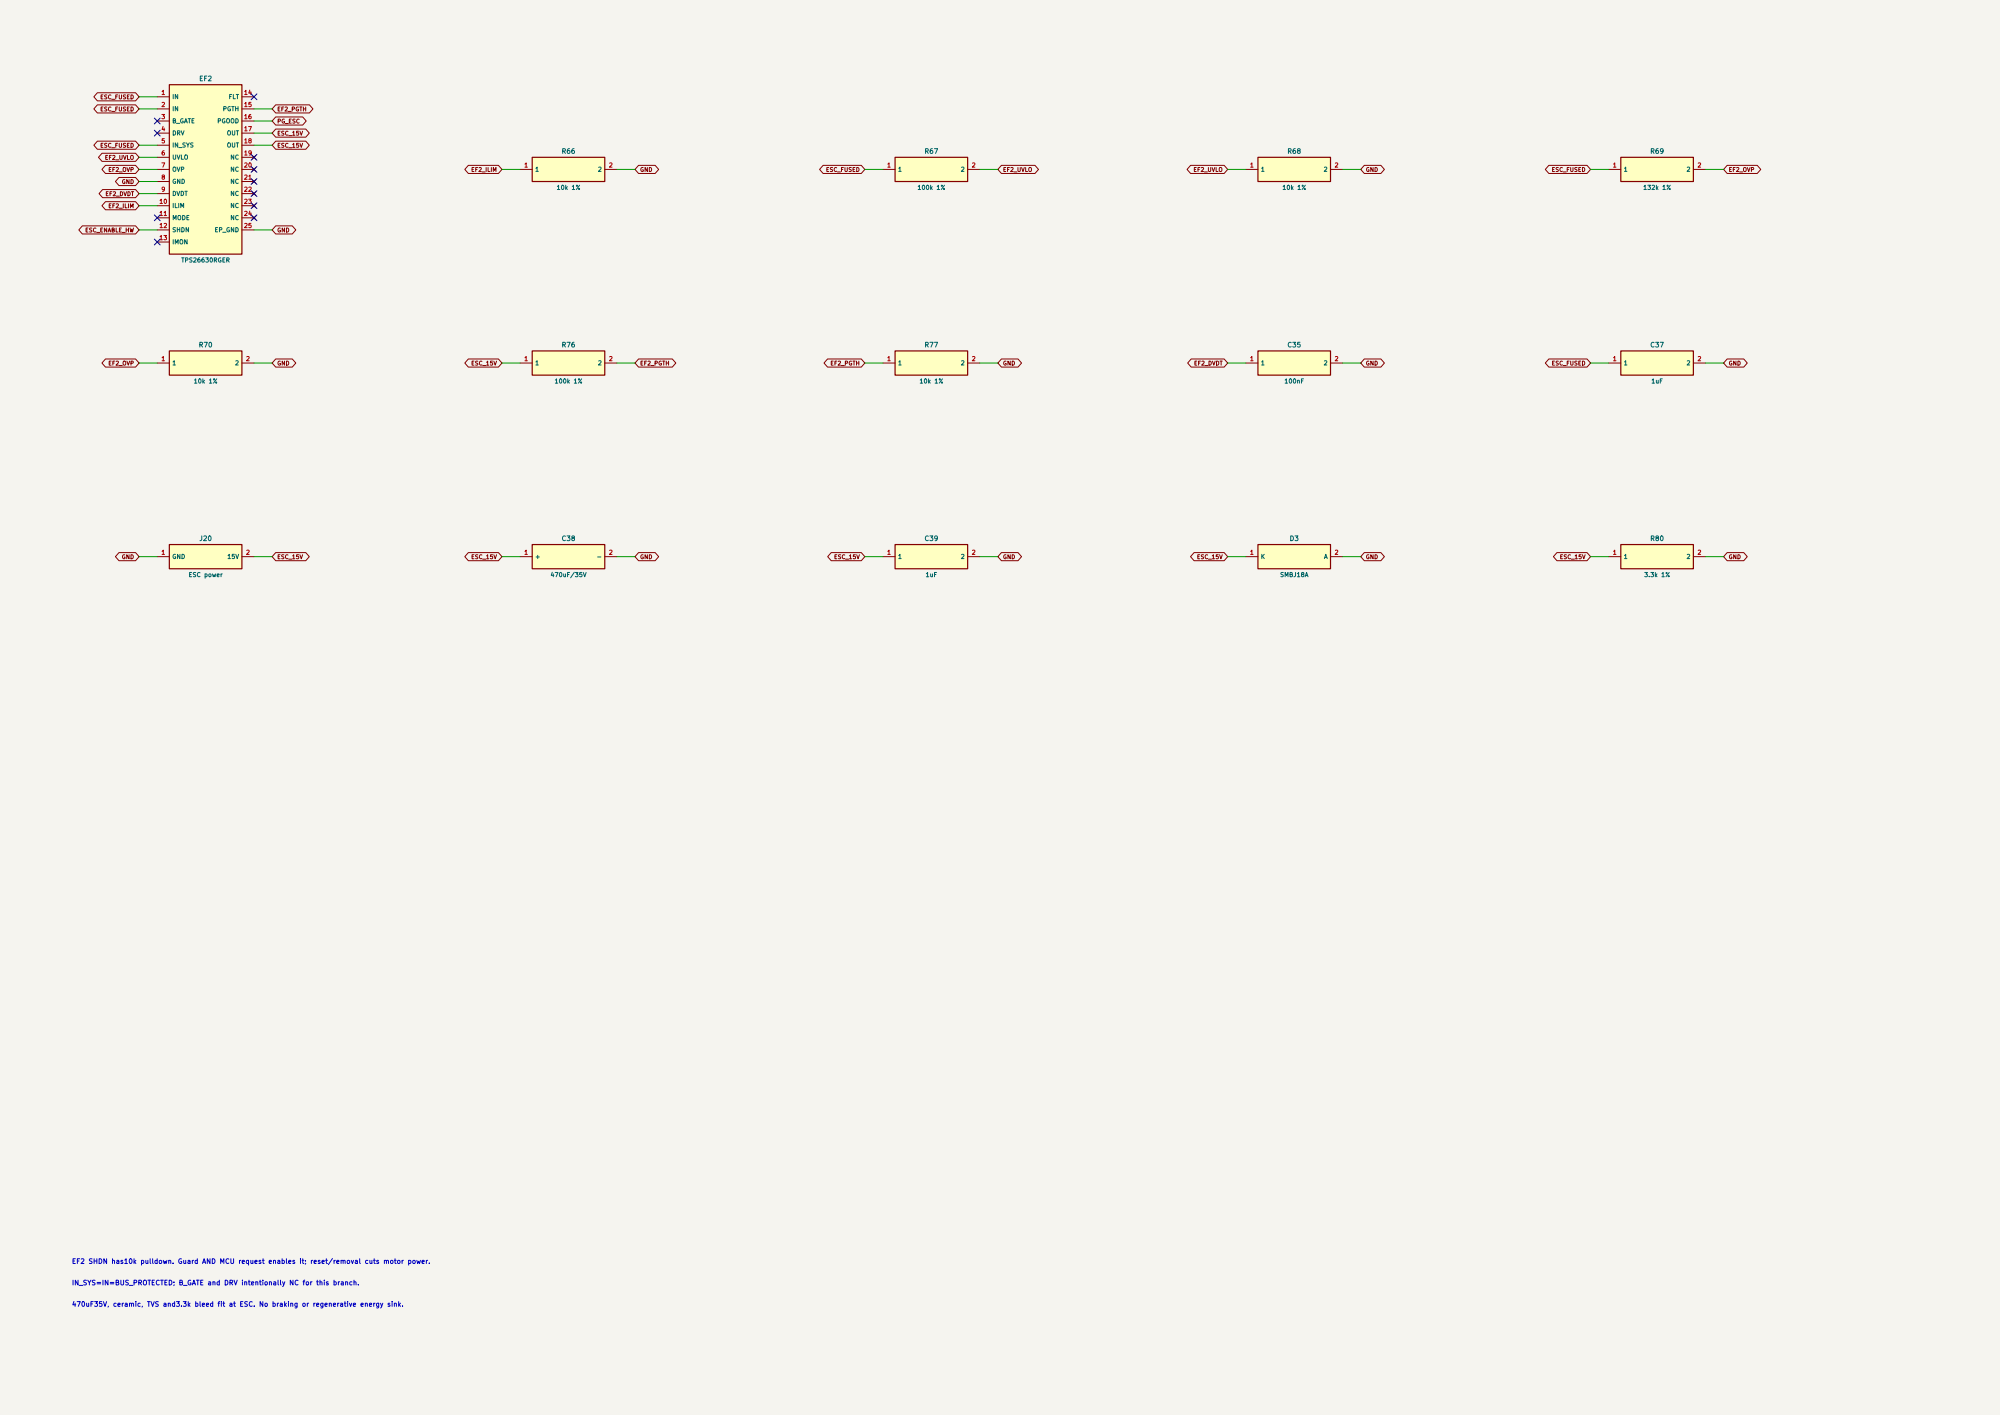
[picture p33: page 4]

470uF35V, ceramic, TVS and3.3k bleed fit at ESC. No braking or regenerative energy sink. EF2 SHDN has10k pulldown. Guard AND MCU request enables it; reset/removal cuts motor power.

IN_SYS=IN=BUS_PROTECTED; B_GATE and DRV intentionally NC for this branch.

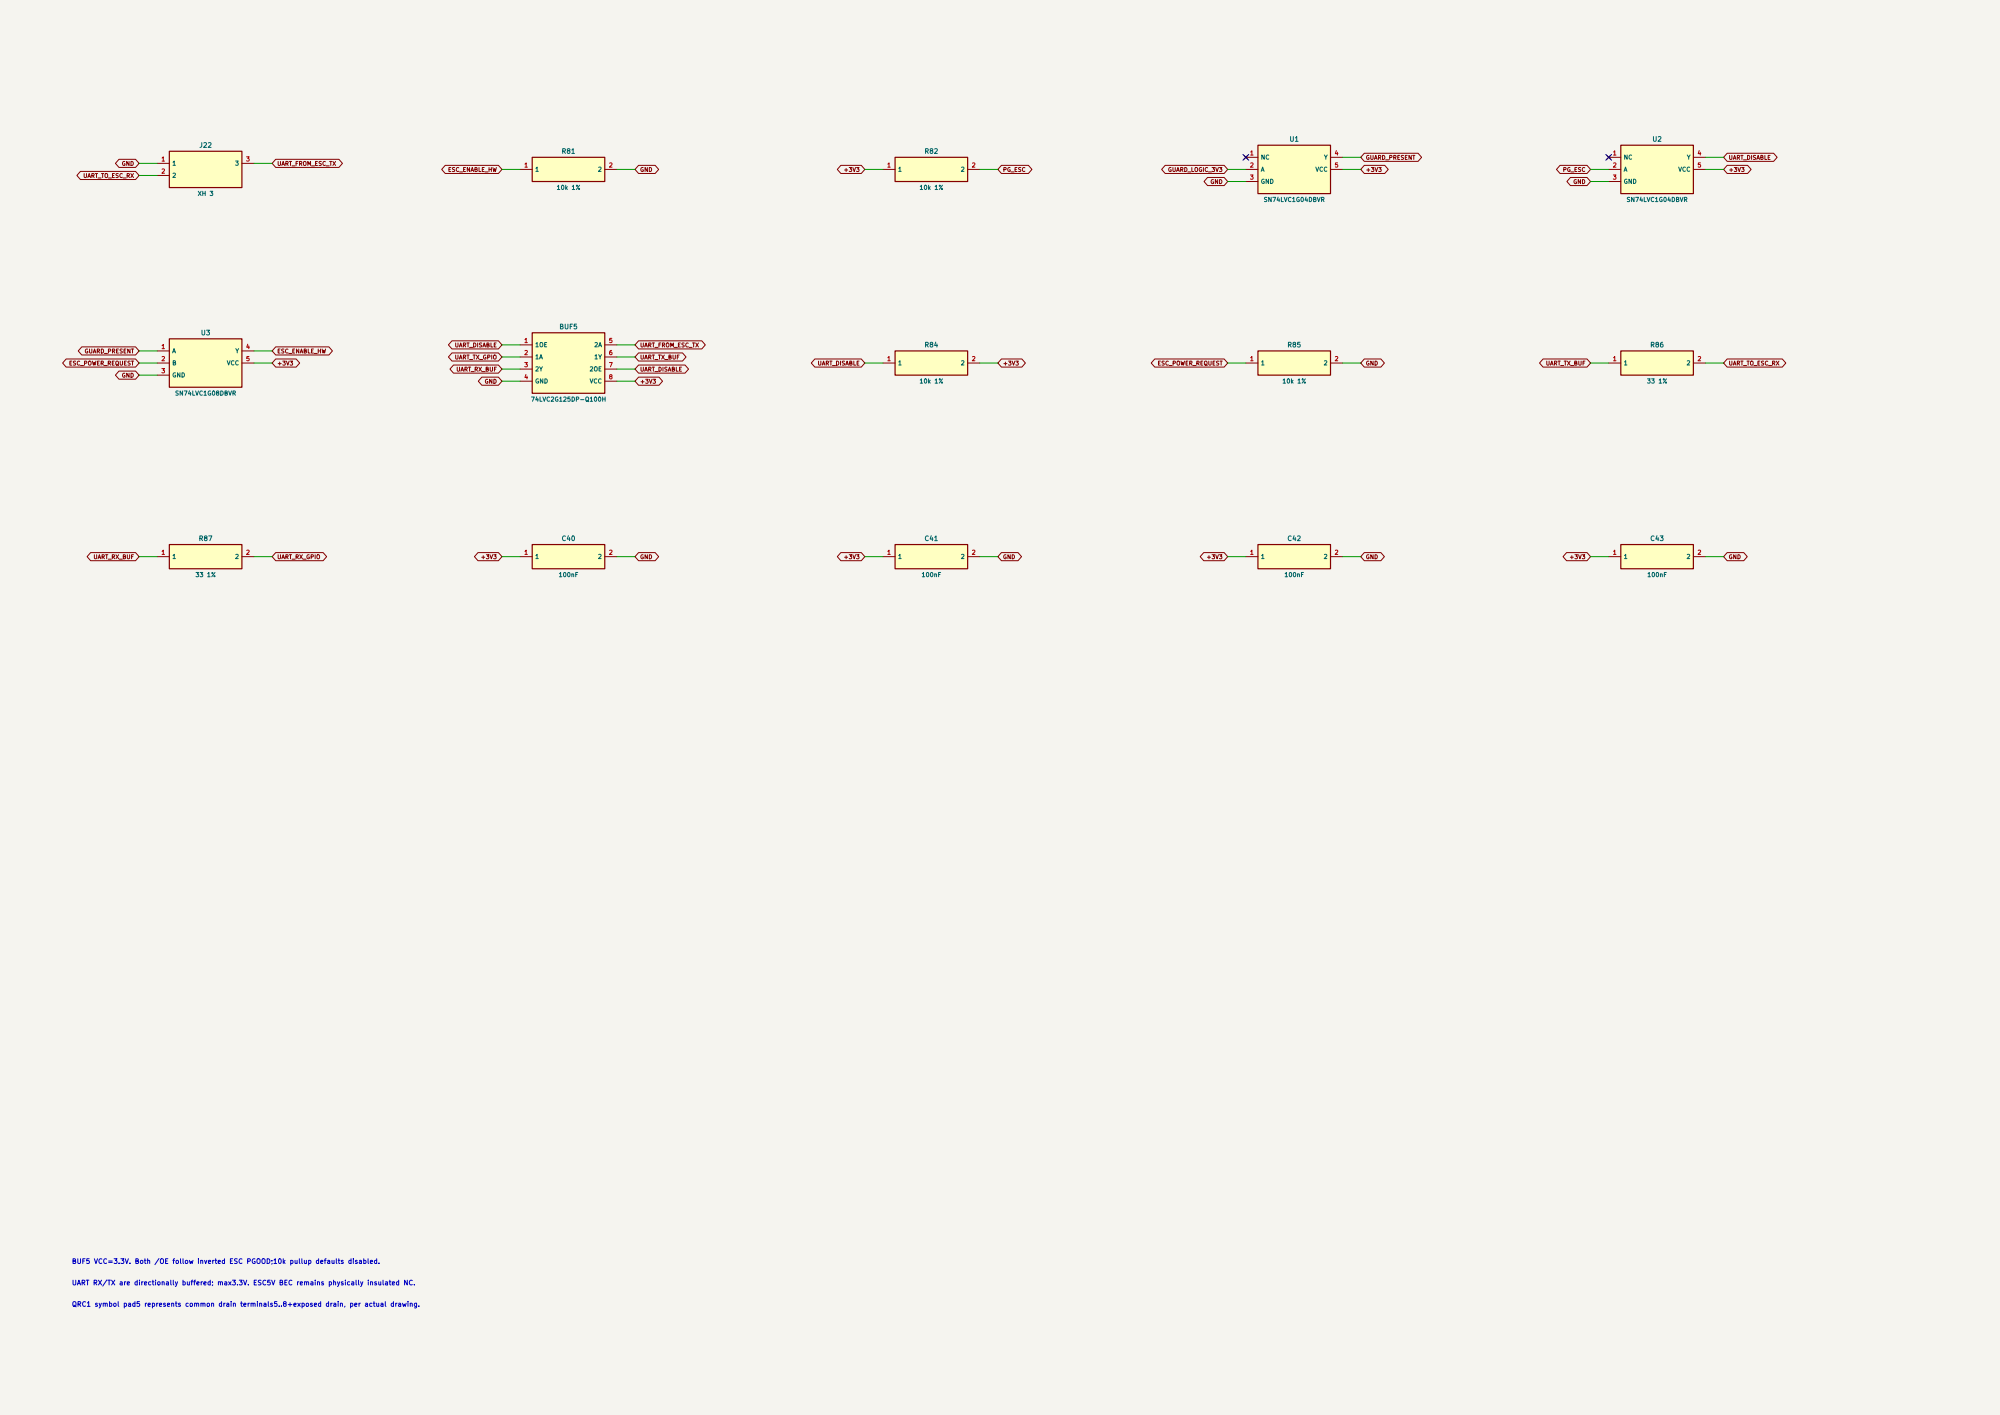
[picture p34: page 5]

QRC1 symbol pad5 represents common drain terminals5..8+exposed drain, per actual drawing. BUF5 VCC=3.3V. Both /OE follow inverted ESC PGOOD;10k pullup defaults disabled. UART RX/TX are directionally buffered; max3.3V. ESC5V BEC remains physically insulated NC.


GPIO8 is50Hz servo PWM; GPIO9 is supply enable. BUF3 follows switched5V. Timed movement and feedback checks bound jam energy; F3 does not replace jam cutoff. Use real supplied20T servo horn; measured feedback table and end stops required.


Eight ambient pixels only. Screen replaces the front speed/power light bars. BUF1 powered from switched ambient5V; its unused channels disabled and grounded.


EN_AMBIENT GUARD_LOGIC_3V3 Guard COM/NO pulls rawguard LOW when grille is present; BUF4 translates it to GP15. J15/J16 are keyed2x10 IDC headers, all20 contacts retained. OLD E3 keyed cable is incompatible. J15 pin n maps Pico physical n; J16 pin n maps physical n+20. Verify ribbon pin1 continuity. R6/R7 DNP until aggregate breakout I2C pullups are measured. J21 optical RPM is DNP.


Filters precede TMUX1511. ADC-side1M pulldowns remain after isolation. SUP1 enables ADC only after3.3V is healthy. Bus/logic scales11.1 and2.1 require calibration.


BUF2 uses unswitched5V. CS/RST pullups never connect5V directly to Pico. C30/R56 fit at screen end. Top64rows reserve status band; wheel phase/countdown remain visible.

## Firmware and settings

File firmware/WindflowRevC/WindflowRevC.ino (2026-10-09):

#include "Control.h"
#include "Hardware.h"
#include "Input.h"
#include "Lighting.h"
#include "Storage.h"
#include "Service.h"
#include <hardware/watchdog.h>
wf::Control controller;
wf::Hardware hardware;
wf::Input input;
wf::Lighting lighting;
wf::Storage storage;
wf::Service service;
uint32_t started=0,lastControl=0,lastSaved=0;
bool bootDecided=false,serviceRequested=false,resetFault=false;
void setup(){
 hardware.begin();input.begin();lighting.begin();Serial.begin(115200);
 started=millis();resetFault=watchdog_caused_reboot();storage.load(controller.settings);
 controller.begin(started,resetFault);watchdog_enable(1000,true);
}
void loop(){
 uint32_t now=millis();hardware.poll(now,controller.settings);wf::Events e=input.poll(now);
 hardware.in.displayReady=lighting.displayReady();
 if(!bootDecided){
  // Only a jumper already fitted at boot plus a continuous 4-second hold can enter service.
  if(now-started<150)serviceRequested=digitalRead(wf::pin::service)==LOW&&input.pressed();
  else if(!serviceRequested||!input.pressed()||digitalRead(wf::pin::service)!=LOW){bootDecided=true;}
  else if(now-started>=4000){bootDecided=true;if(!resetFault)controller.enterService(now);}
 }else{
  if(controller.state!=wf::State::Service){
   if(e.steps){
    uint16_t before=controller.settings.setting;controller.rotate(e.steps);
    // The entry turn and relative dial position are volatile UI state. Only
    // changes to the saved operating setting should schedule a flash write.
    if(controller.settings.setting!=before)controller.markChanged(now);
   }
   if(e.shortPress){if(controller.state==wf::State::Fault)controller.acknowledge(now,hardware.in);else controller.shortPress();controller.markChanged(now);}
   if(e.longPress){controller.longPress();controller.markChanged(now);}
  }else if(e.steps)controller.jogServo(e.steps*(controller.settings.encoderReverse?-5:5),now);
  if(now-lastControl>=wf::kTickMs){lastControl=now;controller.tick(now,hardware.in);}
 }
 hardware.apply(controller.out,controller.settings,now);lighting.poll(now,controller,hardware.in);
 service.poll(now,controller,hardware,lighting,storage);
 // Bounded flash writes briefly pause UART updates; qualify that measured
 // duration below the independent ESC timeout. Never write in a fault/ramp
 // or while panels move. Lost keepalive must make the ESC coast.
 bool stationary=abs(int(hardware.in.servoAdc)-int(controller.feedbackTarget()))<60;
 if(controller.settingsDirty&&controller.state==wf::State::Live&&stationary&&hardware.in.pd15v&&hardware.in.busV>=14.5f&&now-controller.changedAt>=8000&&now-lastSaved>=60000){
  if(storage.save(controller.settings)){controller.settingsDirty=false;lastSaved=now;}
  else lastSaved=now; // Back off instead of repeatedly writing a failing filesystem.
 }
 watchdog_update();
}

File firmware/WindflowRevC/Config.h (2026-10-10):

#pragma once
#include <stdint.h>
#include <math.h>
#include <initializer_list>
namespace wf {
constexpr uint16_t kSchema=5; // 150 mm P2 article: reject earlier 112 mm calibration records.
constexpr uint16_t kRotorDiameterMm=150;
// Prefix of the exact fit article STEP hash, also retained in saved settings.
constexpr uint32_t kRotorArticleTag=0xbf5fd646;
constexpr char kRotorArticleSha256[]="bf5fd64690b8edc7ecac47ac38f1be2bf501f899b063052fc26b7126a108bae2";
// Change only after a contained spin/overspeed and ESC watchdog qualification.
// This distributed prototype build can display/service the system but cannot spin.
#ifndef WF_MOTION_BUILD_QUALIFIED
#define WF_MOTION_BUILD_QUALIFIED 0
#endif
constexpr bool kMotionBuildQualified=WF_MOTION_BUILD_QUALIFIED==1;
constexpr uint8_t kMotorPolePairs=7;
// Commissioning-input sanity bound only. The 150 mm rotor has NO approved RPM.
constexpr float kRotorAnalysisCeilingRpm=5000;
constexpr uint32_t kEscBaud=115200,kEscCommandMs=50,kEscRequestMs=100;
constexpr uint8_t kMainCapacity=16,kAmbientCapacity=8; // mainCount is a legacy reserved field, not LEDs.
constexpr uint16_t kEncoderDetentsPerRev=24,kBoostEntryDetents=24,kBoostControlDetents=24;
constexpr uint16_t kNormalControlDetents=kEncoderDetentsPerRev; // One physical turn from normal zero to maximum.
constexpr uint16_t kScreenWidth=320,kScreenHeight=240,kScreenStatusHeight=64;
constexpr uint16_t kScreenRenderRows=16;
constexpr uint32_t kScreenSpiHz=24000000,kScreenRefreshMs=100,kScreenSliceMs=6;
constexpr uint32_t kTickMs=10,kRampUpMs=1800,kRampDownMs=900;
constexpr float kOutletWidth=104.0f,kOutletHeight=94.0f,kPanelLength=55.0f;
constexpr float kMechanicalMaxAngle=15.0f;
namespace pin {
constexpr uint8_t encoderA=0,encoderB=1,button=2,opticalTach=3,sda=4,scl=5;
constexpr uint8_t escEnable=6,servoPwm=8,servoEnable=9,ambientLed=11;
constexpr uint8_t screenRst=7,screenDc=10,screenBacklight=16;
constexpr uint8_t screenSck=18,screenMosi=19,screenCs=20;
constexpr uint8_t escTx=12,escRx=13,ledEnable=14,guard=15;
constexpr uint8_t service=17;
constexpr uint8_t servoPowerGood=21,motorPowerGood=22;
constexpr uint8_t busAdc=26,servoFeedback=27,logicAdc=28;
}
inline float clamp(float x,float lo,float hi){return fminf(hi,fmaxf(lo,x));}
inline float approach(float x,float target,float step){return x+clamp(target-x,-step,step);}
inline float smooth(float x){x=clamp(x,0,1);return x*x*(3-2*x);}
struct Settings {
 uint32_t rotorArticleTag=kRotorArticleTag;
 uint16_t setting=400;
 uint8_t on=0,night=0,commissioned=0,encoderReverse=0;
 uint8_t rotorQualified=0;
 float boostThreshold=.75f,minAreaRatio=.75f,minSpeedFraction=.30f,maxSpeedFraction=1.0f;
 float rpmAtMax=3000.0f,pressureSoft=18.0f,pressureHard=24.0f;
 float escInputLimitA=1.4f,escPhaseLimitA=3.0f,escPowerLimitW=18.0f;
 float warnC=55.0f,tripC=65.0f,pressureZero=0.0f;
 float busScale=11.1f,logicScale=2.1f;
 uint16_t servoUs[5]={1100,1200,1300,1400,1500};
 uint16_t feedback[5]={600,750,900,1050,1200};
 // Preserve the storage field names: mainBrightness/nightMain now control TFT backlight.
 // mainCount is reserved at 16; the only addressable strip contains eight ambient LEDs.
 uint8_t mainCount=16,ambientCount=8,mainBrightness=60,ambientBrightness=12;
 uint8_t nightMain=0,nightAmbient=0;
 uint16_t reserved=0;
};
inline float maxPanelAngle(const Settings& s){return asinf(kOutletHeight*(1-s.minAreaRatio)/(2*kPanelLength))*180.0f/3.14159265359f;}
bool valid(const Settings& s);
float tableValue(const uint16_t* table,float f);
struct Mapping {float speedFraction=0,closure=0,areaRatio=1,angle=0;};
Mapping mapSetting(const Settings& s);
}

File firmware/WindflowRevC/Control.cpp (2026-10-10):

#include "Control.h"
#include <stdlib.h>
namespace wf {
static_assert(kEncoderDetentsPerRev>0&&kBoostEntryDetents>0&&kBoostControlDetents>0&&kNormalControlDetents>0,"Encoder control increments must be positive");
static_assert(kNormalControlDetents<=600,"Normal grid must have distinct steps at every valid threshold");
bool valid(const Settings& s){
 if(s.rotorArticleTag!=kRotorArticleTag)return false;
 const float f[]={s.boostThreshold,s.minAreaRatio,s.minSpeedFraction,s.maxSpeedFraction,s.rpmAtMax,s.escInputLimitA,s.escPhaseLimitA,s.escPowerLimitW,s.pressureSoft,s.pressureHard,s.warnC,s.tripC,s.pressureZero,s.busScale,s.logicScale};
 for(float v:f)if(!isfinite(v))return false;
 if(s.setting>1000||s.on>1||s.night>1||s.commissioned>1||s.encoderReverse>1||s.rotorQualified>1)return false;
 if(s.boostThreshold<.60f||s.boostThreshold>.90f||s.minAreaRatio<.75f||s.minAreaRatio>.95f)return false;
 if(s.minSpeedFraction<.2f||s.minSpeedFraction>.4f||s.maxSpeedFraction<.6f||s.maxSpeedFraction>1||s.minSpeedFraction>=s.maxSpeedFraction)return false;
 if(s.rpmAtMax<1000||s.rpmAtMax>kRotorAnalysisCeilingRpm||s.pressureSoft<8||s.pressureHard>26||s.pressureHard<s.pressureSoft+3)return false;
 if(s.escInputLimitA<.1f||s.escInputLimitA>1.4f||s.escPhaseLimitA<.1f||s.escPhaseLimitA>3||s.escPowerLimitW<1||s.escPowerLimitW>18)return false;
 if(s.warnC<40||s.warnC>58||s.tripC<s.warnC+5||s.tripC>70||fabsf(s.pressureZero)>2)return false;
 if(s.busScale<10||s.busScale>12.2f||s.logicScale<1.9f||s.logicScale>2.3f)return false;
 if(!s.mainCount||s.mainCount>kMainCapacity||!s.ambientCount||s.ambientCount>kAmbientCapacity)return false;
 if(s.mainBrightness>80||s.ambientBrightness>60||s.nightMain>4||s.nightAmbient>4)return false;
 if(maxPanelAngle(s)>kMechanicalMaxAngle)return false;
 int du=int(s.servoUs[4])-s.servoUs[0],da=int(s.feedback[4])-s.feedback[0];
 if(abs(du)<80||abs(du)>800||abs(da)<120)return false;
 for(int i=0;i<5;i++){
  if(s.servoUs[i]<900||s.servoUs[i]>2100||s.feedback[i]<50||s.feedback[i]>3200)return false;
  if(i&&((int(s.servoUs[i])-s.servoUs[i-1])*du<=0||(int(s.feedback[i])-s.feedback[i-1])*da<=0))return false;
 }
 return true;
}
float tableValue(const uint16_t* table,float f){float x=clamp(f,0,1)*4;int i=int(x);if(i>=4)return table[4];return table[i]+(table[i+1]-float(table[i]))*(x-i);}
Mapping mapSetting(const Settings& s){
 Mapping m;if(!s.on||s.setting==0)return m;
 float u=s.setting/1000.f;
 if(u<=s.boostThreshold)m.speedFraction=s.minSpeedFraction+(s.maxSpeedFraction-s.minSpeedFraction)*u/s.boostThreshold;
 else{
  m.speedFraction=s.maxSpeedFraction;
  float boost=(u-s.boostThreshold)/(1-s.boostThreshold);
  m.areaRatio=1-boost*(1-s.minAreaRatio);
  m.angle=asinf(kOutletHeight*(1-m.areaRatio)/(2*kPanelLength))*180/3.14159265359f;
  m.closure=m.angle/maxPanelAngle(s);
 }
 return m;
}
void Control::resetOutputs(){out=Outputs{};out.servoUs=settings.servoUs[0];}
void Control::transition(State s,uint32_t now){state=s;entered_=now;servoErrorMs_=0;}
uint16_t Control::normalSettingLimit()const{
 // Invalid stored/calibration values still go through the commissioning gate;
 // do not pass NaN to integer conversion while presenting its safe UI fallback.
 return isfinite(settings.boostThreshold)?uint16_t(lroundf(clamp(settings.boostThreshold,0,1)*1000)):750;
}
uint16_t Control::normalGridValue(uint16_t position)const{
 if(position>kNormalControlDetents)position=kNormalControlDetents;
 return uint16_t((uint32_t(normalSettingLimit())*position+kNormalControlDetents/2)/kNormalControlDetents);
}
uint16_t Control::normalGridAtOrBelow()const{
 uint16_t position=0;
 while(position<kNormalControlDetents&&normalGridValue(position+1)<=settings.setting)position++;
 return position;
}
uint16_t Control::normalDetentsRemaining()const{return kNormalControlDetents-normalGridAtOrBelow();}
RotaryMode Control::rotaryMode()const{
 if(state==State::Fault||state==State::Service)return RotaryMode::Normal;
 if(boostControl_)return RotaryMode::Boost;
 return settings.on&&settings.setting>=normalSettingLimit()?RotaryMode::BoostEntry:RotaryMode::Normal;
}
uint16_t Control::entryDetentsRemaining()const{return boostControl_?0:kBoostEntryDetents-entryDetents_;}
float Control::normalPowerFraction()const{
 uint16_t limit=normalSettingLimit();
 return limit?clamp(settings.setting/float(limit),0,1):0;
}
bool Control::boostEntryReady()const{
 return state==State::Live&&settings.on&&settings.setting>=normalSettingLimit()&&
        out.motorEnable&&motorAtMaxConfirmed_&&out.speedFraction>=settings.maxSpeedFraction-.02f&&out.closure<=.001f&&servoOpenConfirmed_&&
        !out.thermal&&!out.boostLimited;
}
void Control::resetRotaryControl(){
 boostControl_=false;entryDetents_=0;boostDetents_=0;
 uint16_t limit=normalSettingLimit();
 if(settings.setting>limit){settings.setting=limit;settingsDirty=true;}
}
void Control::begin(uint32_t now,bool watchdogReset){
 state=State::WaitPower;fault=Fault::None;last_=now;entered_=now;
 powerStable_=0;stallMs_=0;servoErrorMs_=0;pressureMs_=0;rpmErrorMs_=0;
 liveMotor_=false;servoOpenConfirmed_=false;encoderPosition_=0;boostCeiling_=1;resetRotaryControl();
 // Saved boost restores full NORMAL power, with the panels open. A fresh full
 // turn must explicitly authorize boost again after homing/startup completes.
 changedAt=now;resetOutputs();if(watchdogReset)trip(Fault::Watchdog,now);
}
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

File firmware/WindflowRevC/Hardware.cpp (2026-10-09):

#include "Hardware.h"
#include "SensorCodec.h"
#include <Arduino.h>
#include <hardware/i2c.h>
#include <hardware/pwm.h>
#include <hardware/clocks.h>
#include <hardware/sync.h>
namespace wf {
static bool tx(uint8_t a,const uint8_t* b,size_t n){return i2c_write_timeout_us(i2c0,a,b,n,false,2000)==int(n);}
static bool rx(uint8_t a,uint8_t* b,size_t n){return i2c_read_timeout_us(i2c0,a,b,n,false,2000)==int(n);}
static bool reg(uint8_t a,uint8_t r,uint8_t* b,size_t n){return i2c_write_timeout_us(i2c0,a,&r,1,true,2000)==1&&rx(a,b,n);}
static bool temperature(uint8_t addr,float& t){
 uint8_t id[2],b[2];if(!reg(addr,6,id,2)||be16(id)!=0x0054||!reg(addr,5,b,2))return false;
 t=decodeMcp(be16(b));return t>=-10&&t<=125;
}
void Hardware::begin(){
 for(uint8_t p:{pin::escEnable,pin::servoEnable,pin::ledEnable}){pinMode(p,OUTPUT);digitalWrite(p,LOW);}
 for(uint8_t p:{pin::guard,pin::service,pin::motorPowerGood,pin::servoPowerGood})pinMode(p,INPUT_PULLUP);
 analogReadResolution(12);
 // GPIO6 is an eFuse enable only. Never emit the former 25kHz fan signal.
 Serial1.setTX(pin::escTx);Serial1.setRX(pin::escRx);Serial1.begin(kEscBaud);
 gpio_set_function(pin::servoPwm,GPIO_FUNC_PWM);
 pwm_config servo=pwm_get_default_config();pwm_config_set_clkdiv(&servo,clock_get_hz(clk_sys)/1000000.0f);
 pwm_config_set_wrap(&servo,19999);pwm_init(pwm_gpio_to_slice_num(pin::servoPwm),&servo,true);
 pwm_set_gpio_level(pin::servoPwm,0);
 i2c_init(i2c0,100000);gpio_set_function(pin::sda,GPIO_FUNC_I2C);gpio_set_function(pin::scl,GPIO_FUNC_I2C);
 // External pullups are specified in the wiring document.
 pinMode(pin::opticalTach,INPUT); // Reserved optical tach; not fitted or trusted.
}
void Hardware::poll(uint32_t now,const Settings& s){
 if(now-lastFast_>=10){lastFast_=now;
  in.busV=analogRead(pin::busAdc)*(3.3f/4095)*s.busScale;
  in.logicV=analogRead(pin::logicAdc)*(3.3f/4095)*s.logicScale;
  in.servoAdc=analogRead(pin::servoFeedback);
  in.guardClosed=digitalRead(pin::guard)==LOW;
  in.motorPowerGood=digitalRead(pin::motorPowerGood)==HIGH;
  in.servoPowerGood=digitalRead(pin::servoPowerGood)==HIGH;
 }
 // Flooded/malformed UART work is bounded independently of the console.
 for(int n=0;n<64&&Serial1.available();n++)escParser_.feed(uint8_t(Serial1.read()),now,esc_);
 in.escTelemetryValid=escPowered_&&esc_.fresh(now);
 in.rpm=in.escTelemetryValid?esc_.mechanicalRpm():0;
 in.escFetC=esc_.fetC;in.escInputA=esc_.inputA;in.escPhaseA=esc_.motorA;
 in.escDuty=esc_.duty;in.escVoltage=esc_.inputV;in.escFault=esc_.fault;
 if(now-lastPd_>=100){lastPd_=now;uint8_t a,b;
  if(reg(0x08,0,&a,1)&&reg(0x08,1,&b,1)&&decodePd(a,b)){goodPd_=now;in.pd15v=true;}else in.pd15v=false;
 }
 if(now-lastTemp_>=150){lastTemp_=now;
  if(temperature(0x18,in.tempPower)&&temperature(0x19,in.tempMotor)){goodTemp_=now;in.tempsValid=true;}else in.tempsValid=false;
 }
 if(pressureState_==0&&now>=30){const uint8_t stop[]={0x3f,0xf9};tx(0x25,stop,2);pressureStart_=now;pressureState_=1;}
 else if(pressureState_==1&&now-pressureStart_>=10){const uint8_t cmd[]={0x36,0x15};
  if(tx(0x25,cmd,2)){pressureState_=2;pressureStart_=now;}else{pressureState_=0;}}
 else if(pressureState_==2&&now-pressureStart_>=25&&now-lastPressure_>=20){lastPressure_=now;uint8_t b[9];
  if(rx(0x25,b,9)&&decodePressure(b,in.pressurePa)){goodPressure_=now;in.pressureValid=true;}
  else in.pressureValid=false;
 }
 if(now-goodTemp_>400)in.tempsValid=false;
 if(now-goodPressure_>100)in.pressureValid=false;
 // A sensor supply interruption exits continuous mode. Reissue the bounded
 // stop/start sequence after stale data, instead of requiring a system reboot.
 if(pressureState_==2&&now-pressureStart_>1000&&now-goodPressure_>1000)pressureState_=0;
 if(now-goodPd_>250)in.pd15v=false;
}
static bool sendEsc(const uint8_t* payload,size_t n){
 uint8_t b[kVescMaxPayload+5];size_t length=vescFrame(payload,n,b,sizeof(b));
 if(!length||Serial1.availableForWrite()<int(length))return false;
 return Serial1.write(b,length)==length;
}
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

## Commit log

2026-09-08 Add Windflow firmware prototype and engineering foundation
2026-09-10 Fix firmware commissioning gates and define E2 electronics
    [Calibration.h, Config.h, Control.cpp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]
2026-10-03 Integrate checked Rev B fan CAD and purchased hardware in Onshape
    [REF-3mm-hinge-shaft-155mm.step, REF-Bourns-PEC11H-drawing-envelope.step, REF-FS90-FB-approximate-envelope.step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]
2026-10-03 Integrate IPS display and deliberate full-turn boost controls
    [REF-Bourns-PEC11H-drawing-envelope.step, REF-M7x0p75-encoder-panel-nut.step, REF-SDP810-daughterboard-required-outline.step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]
2026-10-05 Improve daily fan controls and preserve brightness calibration
2026-10-09 Checkpoint 150 mm rotor CAD and accumulated Windflow engineering work
    Add the editable native rotor source, independently validated P2 fit article, compact enclosure and passing 1830-pair nominal integration. Preserve Rev C electronics, firmware, prototype studies and 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
    [BOM-fragment.csv, BOM.csv, D42-magnet-pocket-ladder.step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]
2026-10-09 Make vendor CAD placements reproducible from pinned manufacturer models
2026-10-09 Fix and verify all Rev D stage print meshes before assembly export
    [P2-R12-bellmouth-insert.stl, P2-flowing-head-right-INTEGRAL-OUTLET.stl]
2026-10-10 Bind saved calibration to the 150 mm rotor and retain motion inhibition
2026-10-10 Publish the matching motion-inhibited 150 mm firmware image
2026-10-10 Require a matching inhibited firmware profile for Rev D assembly export
2026-10-10 Publish the native seven-part airpath and current product review
2026-10-10 Record checked 150 mm exchange and current requirements audit
2026-10-10 Design retained side USB-C port and validated fit coupon
    [REF-PD-ISO4032-M2-1.step, REF-PD-ISO4032-M2-2.step, REF-PD-ISO4762-M2x6-1.step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]
2026-10-10 Integrate retained USB-C side port and verify the 65-group assembly
    [P2-150mm-rotor-installed-TEST-ONLY.step, P2-R12-bellmouth-insert.step, P2-TPU-carrier-isolation-ring.step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]
2026-10-10 Record the imported Rev D assembly and native interference checkpoint
2026-10-10 Adapt the grille interlock with checked anchors and signal-wire bends
    [P2-fixed-magnet-seat-frame.step, P2-flowing-head-left-INTEGRAL-OUTLET.step, REF-COM-5853-insulated-route.step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]
2026-10-10 Design and verify front-removable grille interlock cartridge
    [P2-fixed-magnet-seat-frame.step, P2-flowing-head-left-INTEGRAL-OUTLET.step, REF-COM-5853-insulated-route.step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]
2026-10-10 Reproduce connected PCB route candidate with native clearance checks
2026-10-11 Integrate front-service interlock cartridge into checked Rev D assembly
2026-10-12 Record 108-instance Onshape cartridge evidence and current requirement status
2026-10-12 Design and verify permanent enclosure print-join candidate
2026-10-12 Preserve wider-power routing and ground-return development
2026-10-12 Recover control signals around reserved wide power copper
2026-10-12 Develop additional ground escapes with explicit remaining design gaps
2026-10-12 Design the SDP810 pressure daughterboard with checked native pin mapping
